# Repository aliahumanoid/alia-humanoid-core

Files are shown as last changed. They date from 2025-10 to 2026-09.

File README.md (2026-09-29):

<p align="center">
  <picture>
    <source media="(prefers-color-scheme: dark)" srcset="docs/media/alia-banner-dark.png">
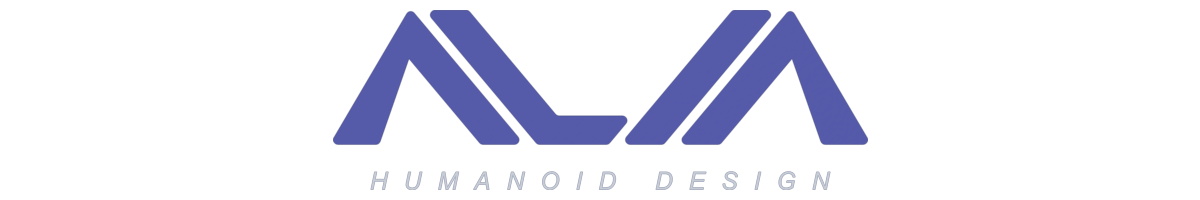
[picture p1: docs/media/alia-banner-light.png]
Alia - Humanoid Design
    
  </picture>
</p>

# Alia Humanoid

**Building humanoid mechanics inside real human proportions.**



<table>
<tr>
<td width="70%">
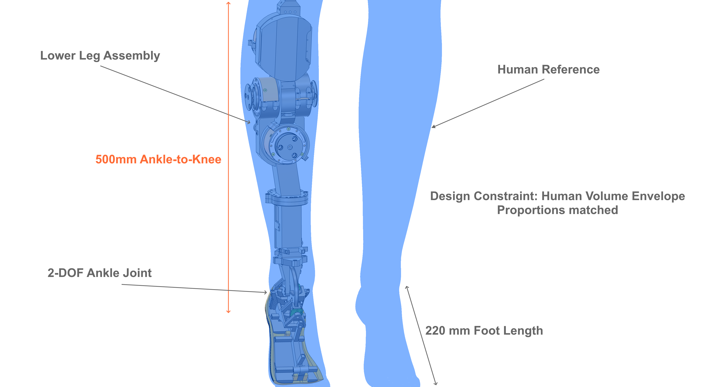
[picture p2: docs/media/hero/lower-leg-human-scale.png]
Lower Leg Human Scale

</td>
<td width="30%">
<a href="https://youtu.be/1Z9GlTnYEFs">
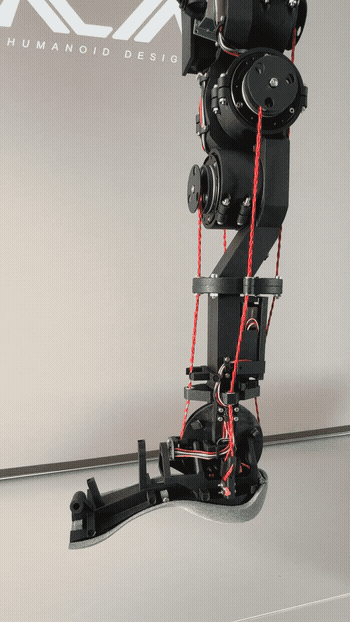
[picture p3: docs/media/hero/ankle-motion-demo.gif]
Ankle motion demo (2 DOF)
  
</a>
</td>
</tr>
<tr>
<td align="center"><i>Lower leg assembly — human scale comparison</i></td>
<td align="center"><i>Right ankle prototype — 2-DOF motion test</i></td>
</tr>
</table>

<table>
<tr>
<td width="65%">
  <a href="https://youtu.be/4jU5Na2z-s8">
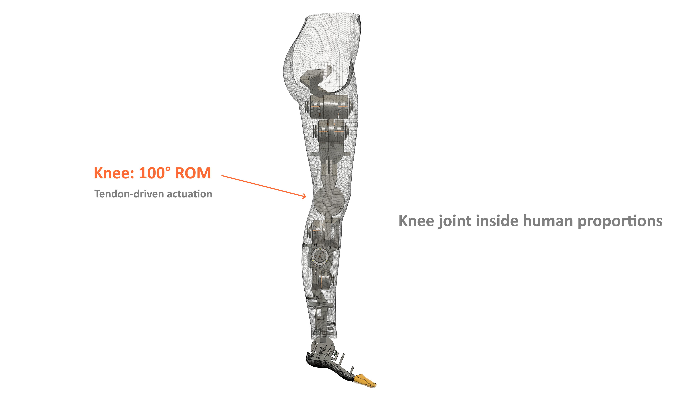
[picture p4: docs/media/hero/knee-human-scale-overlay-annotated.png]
Knee joint overlay (Joint Design Log #002)
    
  </a>
</td>
<td width="35%">
  <a href="https://youtu.be/4jU5Na2z-s8">
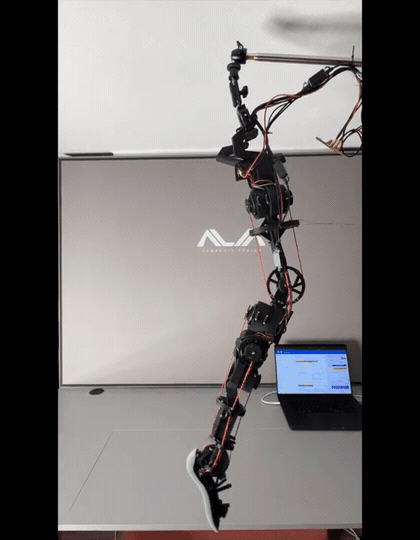
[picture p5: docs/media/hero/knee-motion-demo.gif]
Knee motion demo (1 DOF)
    
  </a>
</td>
</tr>
<tr>
<td align="center"><i>Knee joint overlay — Joint Design Log #002</i></td>
<td align="center"><i>Right knee prototype — 1-DOF motion test</i></td>
</tr>
</table>

<table>
<tr>
<td align="center">
<a href="https://x.com/AliaHumanoid/status/2062545958991265831">
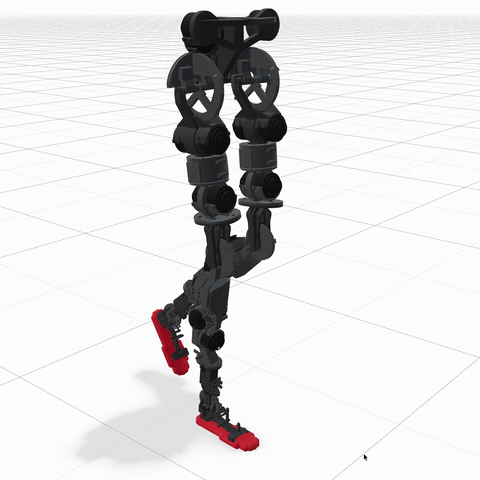
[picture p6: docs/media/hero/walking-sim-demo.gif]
First natural walking gait — physics simulation
  
</a>
</td>
</tr>
<tr>
<td align="center"><i>First natural walking gait — physics simulation, motion-tracking RL (June 2026). Not hardware yet: sim-to-real is gated by remaining hardware.</i></td>
</tr>
</table>

---

## What We're Building

A humanoid robot designed from the ground up to fit within real human dimensions and proportions. 

Most humanoid projects scale UP for easier engineering — more space for motors, looser tolerances, simpler thermal management. We do the opposite: **building inside human constraints** forces design decisions — motor placement, transmission routing, thermal budget — that larger-envelope projects can avoid.

The result? A robot that can fit human environments, wear human clothing, and interact at human scale — using tendon-driven actuation, custom motor placement, and tight mechanical integration.

**Current Phase 0 Focus:** Lower body (hip + knee + ankle) — tendon-driven and direct-drive actuation.

### How We Develop in the Open

This repository carries the **replication core** — firmware, protocols, base host operation, hardware documentation, and results. Advanced lab tooling (calibration campaigns, learning-control experiments, gait tooling) is developed in a private suite and opens progressively as milestones mature. Results, videos, logs, and writeups continue to be published openly. We publish what fails alongside what works; simulation results are labeled as simulation results.

### Latest Updates
- 2026-07: **Development drop** — control-loop rate hardening (bench-validated to 625 Hz on the ankle), joint-map capture improvements, saved-offset warm-boot fast path, MOTION GUARD V2 (gait-aware safety guards; ships disabled, bench validation pending), host impedance-stream `tau_ff` channel — [details](PUBLIC_UPDATES.md)
- 2026-07-18: **Technical note published:** [Deterministic boot-time offset reconstruction for tendon-driven joints](https://aliahumanoid.com/notes/deterministic-boot-offset-reconstruction.html) — method published as prior art
- 2026-07: **License change:** software is GPLv3 from this release (prior MIT snapshots remain MIT); protocol specs stay MIT; hardware licensing unchanged — [rationale](PUBLIC_UPDATES.md)
- 2026-06-04: **First natural walking gait in simulation** — motion-tracking RL on the lower body, ONNX-verified locally — [X thread](https://x.com/AliaHumanoid/status/2062545958991265831) · [details](PUBLIC_UPDATES.md)
- 2026-06: Per-joint power board (`rev_d_power`) bench-validated end-to-end — closed-loop motor control on real hardware, 0.08° tracking error ([report](hardware/electronics/joint_controller_board/rev_d_power/BENCH_VALIDATION_REPORT.md))
- 2026-04: Hip hybrid firmware path implemented (3 DOF / 5 motors) — roll bench bring-up in progress
- 2026-01-26: Joint Design Log #002 (Knee) published — [YouTube](https://youtu.be/4jU5Na2z-s8) · [X thread](https://x.com/AliaHumanoid/status/2015812906101657848)
- 2025-11-13: Joint Design Log #001 (Ankle) published — [YouTube](https://youtu.be/1Z9GlTnYEFs)
- 2025-10-31: Phase 0 public release — [PUBLIC_UPDATES.md](PUBLIC_UPDATES.md)

### Key Features

- 🦶 **2-DOF Ankle Joint**
  Plantarflexion/dorsiflexion (-50° to +25°) + inversion/eversion (±25°)

- 🦵 **1-DOF Knee Joint**
  Full flexion/extension (0° to 100°) with antagonistic tendon pair

- 🦴 **3-DOF Hip Joint (Hybrid)**
  Flexion/extension + abduction/adduction (tendon-driven) + axial roll (direct-drive), 5 motors

- 🧵 **Tendon-Driven Actuation**
  Antagonistic motor pairs with cascade PID, plus single direct-drive for hip roll

- 📏 **Human-Scaled Design**  
  Designed inside real human leg envelope — not scaled up

- ⚙️ **Real Hardware Iteration**  
  PA12 nylon structure (multi jet fusion), pin-and-bushing joints, UHMWPE tendons

- 🖥️ **Jetson Multi-Joint Controller**
  CAN-direct impedance streaming at 50Hz, automated exercise patterns, CAN-first diagnostics

- 🚶 **Walking — In Simulation**
  Natural full-amplitude gait via motion-tracking RL (knee ROM ~57°, foot clearance ~14 cm); sim-to-real gated by remaining hardware

- 📂 **Progressive Open Source**
  Phased licensing roadmap: STL → STEP → CAD source

---

## What Works ✅ / What Doesn't ⚠️

We document **both successes and failures** transparently.

**Current validation snapshot: knee and ankle closed as architecture baselines; per-joint power board bench-validated; hip firmware complete, bench bring-up in progress; natural walking gait achieved in simulation**

### ✅ Validated On Hardware (Phase 0)

- Knee validated as single-controller baseline (`L1` closed) — [Joint Design Log #002](https://youtu.be/4jU5Na2z-s8)
- Ankle validated as single-controller baseline (`L2` closed) — [Joint Design Log #001](https://youtu.be/1Z9GlTnYEFs)
- Multi-joint Jetson coordination operational on bench (`KNEE_RIGHT + ANKLE_RIGHT`) — [milestone log](PUBLIC_UPDATES.md)
- Protocol v1.0 freeze documented for the current knee+ankle bench baseline — [CAN system architecture §4.5](software/docs/CAN_SYSTEM_ARCHITECTURE.md)
- Ankle kinematics achieve target ROM (2 DOF within human envelope) — [joint specs](docs/specs/README.md)
- Knee ROM and tendon-driven position control validated (0-100 degrees)
- UHMWPE tendons validated for current bench loads and pulley compatibility — [tendon specs](docs/specs/TENDON_SPECIFICATIONS.md)
- PA12 structure passes current static/load validation
- Peak torque within biomechanics requirements at the validated bench conditions — [motor specs](docs/specs/MOTOR_SPECIFICATIONS.md)
- Rolling impedance control via CAN with cascade PID on the validated tendon-driven joints — [operational guide](software/docs/SET_IMPEDANCE_OPERATIONAL_GUIDE.md)
- Per-joint power board (`rev_d_power`) validated end-to-end: power rails, hot-swap protection, health telemetry, closed-loop motor control (0.08° tracking error) — [bench report](hardware/electronics/joint_controller_board/rev_d_power/BENCH_VALIDATION_REPORT.md)

### 🧪 Validated In Simulation (Not Hardware)

- Natural full-amplitude walking gait via motion-tracking RL (knee ROM ~57°, foot clearance ~14 cm)
- Policy exported to ONNX and verified locally with observation-parity checks
- Robustness via domain randomization (actuator gains, latency, mass) grounded in measured bench data
- **Honest boundary:** simulation results are simulation results — hardware walking requires foot sole, batteries and full-leg integration first

### 🛠️ Implemented In Firmware, Pending Hip Bench Validation

- Hip hybrid model in firmware (`3 DOF / 5 motors`)
- Per-DOF `DriveType` / `DofCapabilityFlags`
- Direct-drive runtime path for hip axial roll
- Hybrid-aware auto-mapping path (tendon DOFs only)
- `HIP_ROLL_BENCH_*` single-motor bench profiles
- MOTION GUARD V2 — gait-aware divergence/stall guards behind a runtime mode switch (ships in LEGACY mode = current behavior; SHADOW/ACTIVE pending bench validation)

### ⚠️ Still Iterating

- Hip roll bench bring-up and per-DOF gain tuning
- Full hip 3-DOF integrated validation (L3)
- Multi-controller integrated test (L4: hip + knee + ankle on Jetson)
- Walking gait as integrated lower-body system **on hardware**
- Sim-to-real transfer (policy deployment on the onboard computer; gated by foot sole, power boards at scale, batteries)
- Power board high-current stress testing (22A continuous / ~38A peak)

---

## Architecture

```
Jetson host (Python)          RP2350 joint controller (C++)          Motors
SET_IMPEDANCE @50Hz  --CAN-->  core0: encoders (MT6835, SPI)   --CAN--> antagonistic
per-DOF gains/tau_ff           core1: cascade PID + safety              tendon pairs
                               (bench-validated to 625 Hz)              (+ direct-drive hip roll)
```

- [CAN system architecture](software/docs/CAN_SYSTEM_ARCHITECTURE.md) — protocol, IDs, freeze policy
- [SET_IMPEDANCE operational guide](software/docs/SET_IMPEDANCE_OPERATIONAL_GUIDE.md) — the impedance streaming interface
- [Firmware update protocol spec](software/docs/CAN_FIRMWARE_UPDATE_PROTOCOL_SPEC.md) — CAN-based firmware updates

## Build & Run

**Host (runs without hardware):**
```bash
cd software/host && python3 -m venv venv && . venv/bin/activate
pip install -r requirements.txt && python main.py   # web UI on :5001
```

**Firmware (PlatformIO, RP2350 Pico 2):**
```bash
cd software/firmware/joint_controller && pio run
```

Bench bring-up: [Jetson single-controller checklist](software/docs/JETSON_SINGLE_CONTROLLER_BRINGUP_CHECKLIST.md). Minimum bench: one joint controller board, CAN adapter, 24V supply.

## Current Status (Phase 0 — July 2026)

| Component | Status | License | Notes |
|---|---|---|---|
| **Software** | ✅ Public | GPLv3 | Python host + C++ firmware (RP2350 Pico 2); releases before July 2026 remain MIT |
| **Hardware Docs** | ✅ Public | CC BY-NC-ND | Assembly guides, BOM, design specs |
| **STL Files** | ✅ Public | CC BY-NC-ND | 19 files: ankle, lower leg, common components |
| **Electronics** | ✅ Public | CC BY-NC-ND | RP2350 controller board + per-joint power board (KiCad source, Gerber, STEP) |
| **CAD Source** | 📅 Phase 2+ (TBD) | CC BY-SA | Full parametric Fusion 360 timeline |

See our [licensing roadmap](hardware/LICENSE.md) for details on the phased open-source transition.

---

## Quick Links

- 📺 **[YouTube Channel](https://www.youtube.com/@aliahumanoid)** — Design logs, demos, technical breakdowns
- 🐦 **[X/Twitter (@AliaHumanoid)](https://x.com/AliaHumanoid)** — Project updates, iteration logs
- 🌐 **[Website](https://aliahumanoid.com)** — Project overview and roadmap
- 📝 **[Public Updates](PUBLIC_UPDATES.md)** — Public milestone log and release notes
- 📖 **[Documentation](software/README.md)** — Software architecture, protocols, build guides
- 📐 **[Technical Specs](docs/specs/README.md)** — Joint specifications, motor specs, tendon specs
- 🗒️ **[Technical Notes](https://aliahumanoid.com/notes/deterministic-boot-offset-reconstruction.html)** — Method writeups published as prior art

**Evaluating this project? Start here:** (1) watch a [joint design log](https://youtu.be/1Z9GlTnYEFs), (2) read the [boot-reconstruction technical note](https://aliahumanoid.com/notes/deterministic-boot-offset-reconstruction.html), (3) read the firmware control loop (`software/firmware/joint_controller/src/JointController_ControlLoop.cpp`). Issues with findings are welcome.

---

## Gallery

<table>
<tr>
<td width="50%">
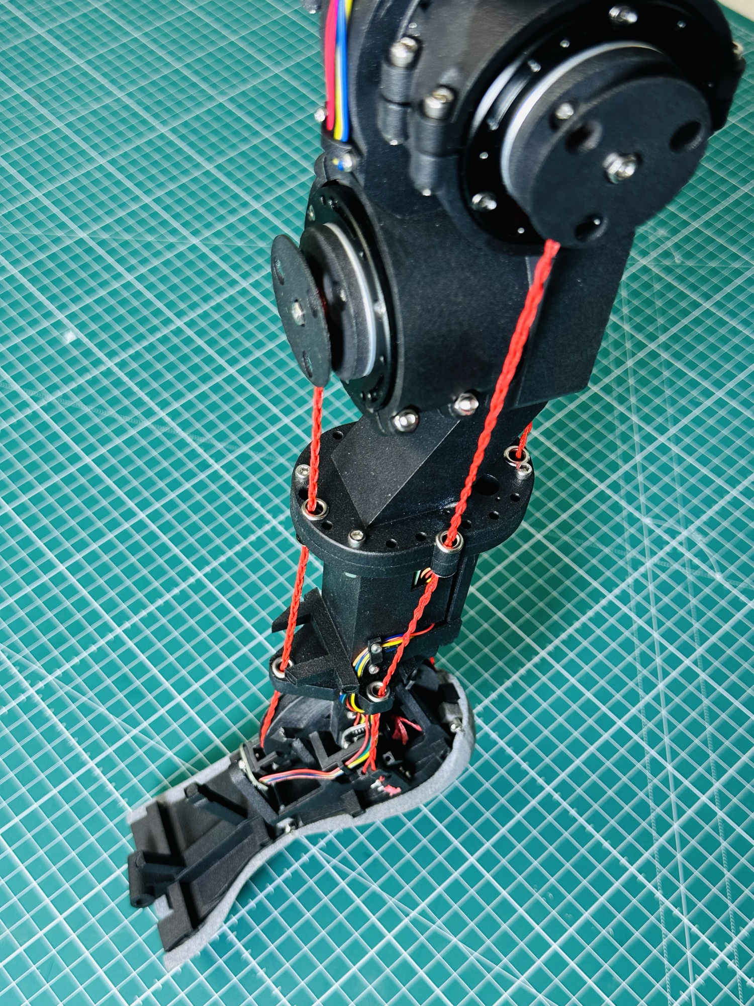
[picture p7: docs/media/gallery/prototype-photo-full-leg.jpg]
Physical Prototype

<p align="center"><i>Physical prototype assembly (Phase 0)</i></p>
</td>
<td width="50%">
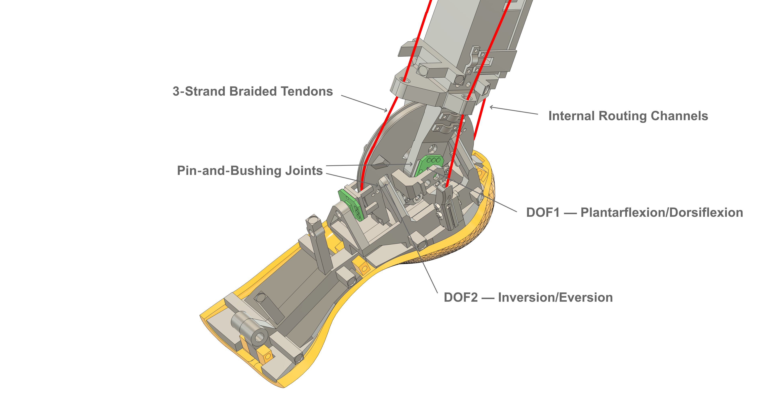
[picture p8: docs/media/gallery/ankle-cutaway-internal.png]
Ankle Internal Mechanisms

<p align="center"><i>Ankle cutaway showing tendon routing</i></p>
</td>
</tr>
</table>

---

## Project Roadmap

### Phase 0 (Current) — Prove the Concept
- **Focus:** Lower body (hip + knee + ankle) validation
- **Release:** Software (GPLv3 from the July 2026 release; earlier snapshots remain MIT), Hardware docs + STL (CC BY-NC-ND)
- **Timeline:** In progress

### Phase 1 — Expand Hardware
- **Focus:** Full leg (hip, knee, ankle), upper body planning
- **Release:** STL → STEP files (CC BY-NC-SA)
- **Timeline:** Planned

### Phase 2 — Full Collaboration
- **Focus:** Complete humanoid system integration
- **Release:** CAD source files (CC BY-SA), governance formalized
- **Timeline:** TBD

### Phase 3 — Open-Core Model
- **Focus:** The software open-core boundary is active now (formalized early, July 2026): this repo = replication core; advanced lab tooling opens progressively as milestones mature
- **Release:** Hardware follows the phased CC roadmap above; private components promote to public at milestone gates
- **Timeline:** Boundary active; promotions ongoing

---

## Follow Progress

This repository documents Phase 0 validation work in public. Small software/docs improvements and evidence-based feedback are welcome. See [CONTRIBUTING.md](CONTRIBUTING.md) for the current collaboration boundary.

**Ground Rules:**
- All commits require DCO sign-off: `git commit -s`
- Use English for code/comments/issues
- Follow conventional commit format (`feat:`, `fix:`, `docs:`, etc.)

**Current Accepted PR Scope:**
- 🐛 Bug reports and fixes
- 📖 Documentation improvements (clarity, examples, translations)
- 🧪 Testing and validation reports (especially hardware replication)
- 💡 Feature proposals (via issues first)

**Not Yet Open As PR Surface:**
- Hardware geometry changes to STL/CAD assets
- Canonical hardware design modifications while the public hardware release remains STL-only

For hardware design ideas, replication findings, and geometry feedback, open an issue first with evidence, measurements, or photos.

---

## References & Acknowledgments

### Control Architecture

The cascade control structure implemented for antagonistic tendon-driven actuation is inspired by the approach described in:

> **Lukić B., Jovanović K., Šekara T. B. (2019).**  
> *Cascade Control of Antagonistic VSA — An Engineering Control Approach to a Bioinspired Robot Actuator.*  
> Frontiers in Neurorobotics, Vol. 13, Article 69.  
> DOI: [10.3389/fnbot.2019.00069](https://doi.org/10.3389/fnbot.2019.00069)

The original paper presents a double-loop cascade architecture for simultaneous position and stiffness control of an antagonistic Variable Stiffness Actuator (VSA). 

In Alia's implementation, this concept has been extended and generalized to a multi-DOF humanoid control system, featuring:
- Coordinated cascade loops for multiple joints
- Per-DOF tuning of PID gains (inner loop: motor position, outer loop: joint position)
- Dynamic modulation of cascade influence and stiffness reference
- Synchronized trajectory generation for agonist–antagonist motor pairs

This implementation is an independent engineering development released under the GNU GPLv3 (releases before July 2026: MIT).

---

## License

- **Software (firmware + host):** [GNU GPLv3](LICENSE) from the July 2026 release onward. Releases published before July 2026 were MIT and remain MIT — irrevocable for anyone who obtained them.
- **Protocol specifications** ([CAN system architecture](software/docs/CAN_SYSTEM_ARCHITECTURE.md), [firmware-update protocol](software/docs/CAN_FIRMWARE_UPDATE_PROTOCOL_SPEC.md)): **MIT**, so third-party tools can integrate without copyleft obligations.
- **Hardware:** unchanged — see [hardware/LICENSE.md](hardware/LICENSE.md) for the phased CC roadmap.

By contributing code, you license it under GPLv3 (DCO sign-off required). Hardware design feedback is welcome now; canonical hardware geometry changes will open later as the hardware release surface expands.

---

### How the pieces fit (what protects what)

| Layer | License / instrument | What it means in practice |
|---|---|---|
| Firmware + host software | **GPLv3** (July 2026 onward; earlier snapshots remain MIT) | Commercial use is allowed; modified versions must stay GPLv3; no locked-down derivatives |
| Protocol specifications | **MIT** | Third-party tools can implement the protocols without copyleft obligations |
| Hardware (STL, docs, BOM) | **CC BY-NC-ND 4.0** today → CC BY-NC-SA (STEP) → CC BY-SA (CAD source) | Print and study now; no commercial use or derivatives yet; opens in phases, see [hardware/LICENSE.md](hardware/LICENSE.md) |
| Published technical notes | **Public prior art** | Keeps the methods free for everyone to use: nobody can patent them later. Prior art does not restrict copying; the licenses above do |
| Name and logo | Not covered by any of the above | Trade mark rules apply separately |

ALIA HUMANOID is a registered EU trade mark (EUTM 019380142). The name and the brand are not covered by the open licenses of this repository.

## Developer Certificate of Origin (DCO)

All commits must include a `Signed-off-by` line to certify you have the right to contribute:

```bash
git commit -s -m "feat: add ankle calibration script"
```

This asserts compliance with the [Developer Certificate of Origin](https://developercertificate.org/).

---

## Contact

- **General:** info@aliahumanoid.com
- **Issues/PRs:** Use GitHub issues and pull requests
- **Social:** [@AliaHumanoid](https://x.com/AliaHumanoid) on X/Twitter

---

**Project Status:** Phase 0 active development

---

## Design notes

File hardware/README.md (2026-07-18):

# Alia Humanoid Hardware

**Project Phase**: 0 (public lower-body validation)  
**Status**: Lower leg assets preparation (ankle validated)  
**Current Public Hardware Release**: STL/docs/BOM only  
**License**: CC BY-NC-ND 4.0 → See [LICENSE.md](LICENSE.md)

---

## Overview

This directory contains all mechanical design assets for the Alia humanoid robot. CAD files, STL exports, URDF models, and manufacturing documentation are organized following ROS/URDF naming conventions for seamless simulation integration.

If you just want the currently released printable STL parts, start here:

- [Simple STL Release](stl/phase0_rev_a/)
- [Mechanical Release Guide](mechanical/README.md)
- [Electronics Hardware](electronics/)
- [Hardware License](LICENSE.md)

## Directory Structure

```
hardware/
├── urdf/              → URDF/xacro files for robot simulation
│   ├── alia.urdf      → Complete robot description
│   ├── materials.xacro
│   └── joints/        → Individual joint URDF macros
│
├── meshes/            → 3D meshes for visualization & collision
│   ├── visual/        → High-quality STL for RViz/Gazebo rendering
│   └── collision/     → Simplified collision meshes (performance)
│
├── stl/               → Simple public STL release entrypoint
├── mechanical/        → CAD sources & manufacturing files
│   ├── BOM.csv        → Bill of Materials (complete parts catalog)
│   ├── lower_leg/     → Shank structure (tibia/fibula analog)
│   ├── ankle/         → 2-DOF ankle joint (validated Phase 0)
│   └── foot/          → Foot base + phalanges (5 toes)
│
└── electronics/       → Public PCB designs (controller logic board + passive hubs)
    ├── joint_controller_board/  → RP2350 controller logic board (`rev_d_logic`)
    ├── MT6835_hub_rev_a/        → Passive encoder SPI hub
    └── motor_can_power_hub_rev_a/ → Passive CAN/power distribution hub
```

---

## Released STL Files (Phase 0)

**19 files currently available for printing.**

Simple download path:

- [hardware/stl/phase0_rev_a](stl/phase0_rev_a/)

Traceable mechanical source paths are listed below.

### Right Ankle Assembly (6 parts)
- `ankle_inversion_eversion_frame.stl` — Main frame for inversion/eversion motion
- `ankle_plantar_dorsal_frame.stl` — Frame for plantarflexion/dorsiflexion motion  
- `ankle_tendon_holder_left.stl` — Tendon anchor point (left side)
- `ankle_tendon_holder_right.stl` — Tendon anchor point (right side)
- `ankle_tendon_holder_inversion_left.stl` — Inversion tendon mount
- `ankle_tendon_holder_inversion_right.stl` — Inversion tendon mount

### Right Lower Leg Assembly (4 parts)
- `lower_leg_frame_upper.stl` — Upper leg structure
- `lower_leg_frame_lower.stl` — Lower leg structure
- `lower_leg_encoder_board_cover.stl` — Encoder electronics cover
- `lower_leg_power_board_cover.stl` — Power distribution cover

### Common Components (9 parts)
**Motor mounts:**
- `motor_mount_mg4005.stl` — Mount for LKM MG4005 motors
- `motor_mount_mg5010.stl` — Mount for LKM MG5010 motors

**Pulleys:**
- `pulley_10mm.stl` — 10mm diameter pulley for tendon routing
- `pulley_18mm.stl` — 18mm diameter pulley for tendon routing

**Sensor mounts:**
- `encoder_mount_mt6835_flat.stl` — MT6835 encoder mount (flat)
- `encoder_mount_mt6835_with_spacer.stl` — MT6835 encoder mount (with spacer)
- `shaft_holder_flat.stl` — Shaft retainer (flat version)
- `shaft_holder_with_spacer.stl` — Shaft retainer (with spacer)

**Cable management:**
- `cable_clamp_10mm.stl` — Cable routing clamp

**Material:** PA12 (nylon) recommended. Print settings and BOM available in component directories.

---

## Naming Convention

**Standard**: ROS/URDF snake_case for maximum compatibility with robotics ecosystem.

### File Naming Format
```
{body_part}_{component}_{descriptor}.{ext}

Examples:
- lower_leg_shank_upper.step
- ankle_pulley_proximal.stl
- foot_toe_01.step (big toe / hallux)
```

### Left/Right Handling
**Directory-based separation** (not filename suffix):
```
mechanical/ankle/
├── left/
│   └── rev_a/
│       └── stl/
│           └── ankle_pulley_proximal.stl  ← Same name for L/R
└── right/
    └── rev_a/
        └── stl/
            └── ankle_pulley_proximal.stl  ← Different path, identical filename
```

**Rationale**: Enables URDF xacro macros to reference parts with parameter substitution:
```xml
<mesh filename="package://alia_description/meshes/ankle/${side}/ankle_pulley_proximal.stl"/>
```

### Revision Management
```
mechanical/{joint}/{side}/
├── rev_a/     → Initial design (current)
├── rev_b/     → Future iteration
└── rev_c/     → Further refinement
```

**Revision Policy**:
- Increment letter (A→B→C) when **geometry/dimensions change**
- Track material/finish changes in BOM notes (no new revision)
- Keep all revisions in Git for traceability

## Contributing

For the current STL-only release, hardware feedback is welcome but canonical hardware geometry changes are not part of the active PR surface yet.

Current in-scope contributions:
1. Replication feedback with measurements, photos, and failure notes
2. Documentation fixes and clarifications
3. BOM corrections or missing-public-data corrections
4. Issues that identify manufacturability or assembly problems

When STEP/CAD sources are released, hardware geometry collaboration will expand. See the root [CONTRIBUTING.md](../CONTRIBUTING.md) and [LICENSE.md](LICENSE.md) for the current boundary.

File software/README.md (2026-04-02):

# Software Stack

This directory contains the public software stack for the Alia project.

Structure
```
software/
├─ host/                 # Python host application (Flask + Socket.IO)
└─ firmware/             # Embedded firmware projects (PlatformIO)
```

Current Status
- Firmware and host application integrated and operational
- Repository structure consolidated for public development
- Build system and tooling fully configured

Operational docs
- `docs/CAN_SYSTEM_ARCHITECTURE.md` - wire-level host↔controller protocol and transport architecture
- `docs/CAN_DIAGNOSTICS_OPERATIONAL_GUIDE.md` - CAN-first observability workflow for integrated experiments
- `docs/SET_IMPEDANCE_OPERATIONAL_GUIDE.md` - operational semantics for impedance commands

Dev Runner

Use the Makefile to switch between running the host app and building firmware.

- `make run MODE=host` — run Python host (creates venv, installs deps)
- `make run MODE=firmware-controller ENV=pico2` — build controller firmware
- `make fw-monitor-controller PORT=/dev/tty.usbmodemXXXXX` — serial monitor 115200

PlatformIO path (optional)
- If you don't have `pio` globally, PlatformIO is also installed inside the host venv.
- Pass `PIO=host/.venv/bin/pio` to Makefile targets, e.g.:
  - `make run MODE=firmware-controller ENV=pico2 PIO=host/.venv/bin/pio`

Flash & Monitor via VS Code
- You can use the PlatformIO VS Code extension to upload/monitor without CLI.
- Open `software/firmware/joint_controller` as a project in VS Code and use the PIO toolbar (Upload, Monitor).

Host notes
- The dev server uses Werkzeug with `allow_unsafe_werkzeug=True` for local runs only.
- For production-like tests, prefer a proper SocketIO server (e.g., `eventlet` or `gunicorn` + `gevent`).

Host quickstart (manual)
- `cd software/host && python3 -m venv .venv && source .venv/bin/activate`
- `pip install -r requirements.txt`
- `python main.py` then open `http://localhost:5001`

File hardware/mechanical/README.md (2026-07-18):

# Mechanical Release Guide

This is the direct entrypoint for the currently released mechanical assets.

## Start Here

The current public Phase 0 release is centered on the **right lower leg + right ankle** plus reusable common hardware.

For the simplest STL download path, use:

- [hardware/stl/phase0_rev_a](../stl/phase0_rev_a/)

Released printable parts live in:

- [ankle/right/rev_a/stl](ankle/right/rev_a/stl)
- [lower_leg/right/rev_a/stl](lower_leg/right/rev_a/stl)
- [common](common)
- [BOM.csv](BOM.csv)

## What Is Released Now

- Right ankle STL set
- Right lower-leg STL set
- Common motor mounts, pulleys, sensor mounts, and cable-management parts
- Phase 0 BOM

## What Is Not a Public Build Surface Yet

These directories exist for structure and future release flow, but they are not the main public printing path today:

- `ankle/left/`
- `lower_leg/left/`
- `foot/`
- `rev_a/cad/`
- `rev_a/docs/`
- `rev_a/manufacturing/`

Treat them as repository structure, work-in-progress, or future release surface unless a component directory explicitly says otherwise.

## Practical Path

If you want to print the current public lower-body set:

1. Read [hardware/README.md](../README.md) for scope and license.
2. Use the STL folders listed above.
3. Cross-check quantities and hardware callouts in [BOM.csv](BOM.csv).
4. Use [PUBLIC_UPDATES.md](../../PUBLIC_UPDATES.md) for release context.

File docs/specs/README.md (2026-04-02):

# Technical Specifications — Alia Humanoid

> **Status**: Phase 0 Reference Documentation  
> **Last Updated**: 2026-03-07

---

## Overview

This directory contains authoritative technical specifications for all mechanical subsystems of the Alia humanoid robot.

**Purpose**:
- Documentation consistency across public specs and implementation
- Public technical reference and content creation
- Future collaborator onboarding
- BOM management

---

## Specification Documents

| Document | Scope | Status |
|---|---|---|
| [ANKLE_SPECIFICATIONS.md](ANKLE_SPECIFICATIONS.md) | 2-DOF ankle joint (kinematics, motors, transmission) | ✅ Validated |
| [KNEE_SPECIFICATIONS.md](KNEE_SPECIFICATIONS.md) | 1-DOF knee joint | ✅ Validated |
| [MOTOR_SPECIFICATIONS.md](MOTOR_SPECIFICATIONS.md) | QDD motor classes (50mm, 40mm) | Phase 0 |
| [TENDON_SPECIFICATIONS.md](TENDON_SPECIFICATIONS.md) | UHMWPE tendons, routing, terminations | Phase 0 |

---

## Robot Parameters

| Parameter | Value |
|---|---|
| Target Height | 175 cm |
| Target Mass | 25 kg |
| Design Gait | Slow walking |
| Actuation | Antagonistic tendon-driven |

---

## Validation Status

| Joint | ROM | Torque | Control | Integration |
|---|-----|---|---|---|
| Ankle | ✅ | ✅ | ✅ | 🔄 In progress |
| Knee | ✅ | ✅ | ✅ | 🔄 In progress |
| Hip | — | — | — | ⏳ Planning |

---

## Document Conventions

### Status Indicators

| Symbol | Meaning |
|---|---|
| ✅ | Validated / Complete |
| ⚠️ | Needs attention / Partial |
| 🔄 | In progress |
| ⏳ | Planned / Future |
| [TBD] | To Be Determined |

### Units

- Linear: mm (millimeters)
- Angular: degrees (°)
- Torque: Nm (Newton-meters)
- Force: N (Newtons)
- Mass: g or kg
- Speed: RPM or °/s

---

## Related Documentation

| Location | Content |
|---|---|
| `../../software/docs/CAN_SYSTEM_ARCHITECTURE.md` | CAN architecture, protocol, and streaming |
| `../../hardware/mechanical/BOM.csv` | Bill of Materials |
| `../../software/firmware/` | Controller firmware |

---

## Contributing

Specification updates require:
1. Engineering validation (test data)
2. Decision-log entry (if disclosure-sensitive)
3. Version increment in document control section

---

**Next Review**: After next lower-body validation checkpoint

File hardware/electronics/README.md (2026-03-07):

# Alia Humanoid Electronics

**Status:** Public release scoped to the current controller logic board and two passive hubs  
**License:** CC BY-NC-ND 4.0 (Phase 0) → See [hardware/LICENSE.md](../LICENSE.md)

---

## Overview

This directory contains the electronics currently exposed in the public repository. Older controller revisions and internal support files are intentionally excluded from publication.

## Published Boards

### `joint_controller_board/rev_d_logic`

Main RP2350 logic/control board for one joint.

- RP2350 Pico 2 host module
- Two onboard CAN channels (`MCP2515 + SN65HVD230`)
- RJ45 interface for encoder and power/safety breakout
- KiCad source, BOM, and current fabrication package

### `MT6835_hub_rev_a`

Passive encoder hub that fans out up to three MT6835 SPI encoders into the RJ45 encoder port used by `rev_d_logic`.

- KiCad source
- BOM
- Current fabrication package

### `motor_can_power_hub_rev_a`

Passive CAN/power distribution board for motor wiring.

- XT60 power input
- CAN input terminal block
- Five motor harness outputs
- KiCad source, BOM, and current fabrication package

## Directory Structure

```text
electronics/
├── joint_controller_board/
│   └── rev_d_logic/
├── MT6835_hub_rev_a/
└── motor_can_power_hub_rev_a/
```

---

**Questions?** Contact us at info@aliahumanoid.com

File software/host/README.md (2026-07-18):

# Host Application (Python/Flask)

Web-based control interface for the Alia humanoid joint controller system. This application provides real-time monitoring, PID tuning, auto-mapping, and multi-DOF movement control.

## Features

- **Real-time Joint Control**: Web UI for controlling multiple joints with up to 3 DOF each
- **PID Tuning**: Live adjustment of inner and outer loop PID parameters
- **Auto-Mapping**: Automatic calibration and linear equation generation
- **Multi-DOF Movements**: Coordinated movements with different path types and synchronization strategies
- **Encoder Testing**: Real-time encoder data streaming and visualization
- **Serial Management**: Multi-device serial communication with automatic port detection
- **Structured CAN Diagnostics**: Per-joint health, fault, event, and snapshot history persisted as JSONL

## Quick Start

**Requirements**: Python 3.11+

```bash
cd software/host
python3 -m venv .venv && source .venv/bin/activate
pip install -r requirements.txt
python main.py
```

Open browser at: `http://localhost:5001`

## Joint Configuration Sync

The host application automatically loads joint definitions from `software/joint_config.json`, which is generated from the firmware's `config_presets.h`. This ensures firmware and host stay synchronized.

**To update joint configurations:**
1. Edit `software/firmware/joint_controller/include/config_presets.h`
2. Run: `python software/scripts/extract_joint_config.py`
3. Restart the host application

See `software/docs/JOINT_CONFIG_SYNC.md` for details.

For integrated experiments and Jetson bring-up, see
`software/docs/CAN_DIAGNOSTICS_OPERATIONAL_GUIDE.md`.

## Project Structure

- `main.py` - Application entry point
- `config.py` - Configuration (loaded from joint_config.json)
- `routes.py` - Flask API routes
- `diagnostic_history.py` - JSONL persistence for structured CAN diagnostics
- `bench_diagnostics.py` - Windowed summaries for bench diagnostic JSONL histories
- `serial_handler.py` - Serial protocol implementation
- `serial_manager.py` - Multi-device serial management
- `templates/` - HTML templates (Alia Joint Controller UI)
- `static/` - JavaScript, CSS, images
- `logs/` - Session logs (gitignored)
- `mapping_data/` - Auto-mapping data storage (local runtime data, gitignored)
- `can_config.json` - Saved CAN interface selection (created locally, gitignored)

## Development Workflows

### Using Makefile (Recommended)

From `software/` directory:
```bash
make run MODE=host
```
This automatically creates venv, installs dependencies, and runs the server.

### VS Code

Open the repository root or `software/host/`, select the local `.venv` interpreter, and run `main.py`.

### Firmware Builds (Optional)

Build firmware from the same Makefile:
```bash
make run MODE=firmware-controller ENV=pico2
```

If PlatformIO is not in PATH, specify venv:
```bash
PIO=host/.venv/bin/pio make run MODE=firmware-controller ENV=pico2
```

### Flash & Monitor via VS Code

Use PlatformIO extension in VS Code:
1. Open `software/firmware/joint_controller`
2. Use PIO toolbar to upload and monitor

## Environment Variables

- `FLASK_HOST` - Server host (default: `0.0.0.0`)
- `FLASK_PORT` - Server port (default: `5001`)
- `FLASK_DEBUG` - Debug mode (default: `False`)
- `BAUD_RATE` - Serial baud rate (default: `115200`)

## Notes

- Logs are written under `logs/` (gitignored)
- Structured diagnostic histories are written under `logs/diagnostic_history/` (gitignored)
- `mapping_data/` stores auto-mapping results (gitignored)
- `can_config.json` is created after a successful CAN connection and remains local (gitignored)
- Dev server uses `allow_unsafe_werkzeug=True` for Flask-SocketIO compatibility (local dev only)
- On macOS with a CANable flashed to `candleLight`, the reliable host path is
  currently `interface: candle` at `500 kbps`. The repo default still points to
  `slcan`, so bench runs may require a local config override.
- On the same macOS bench, USB enumeration can be visible at the OS level while
  process-local autodetect still returns no CAN adapters. If that happens,
  verify the device in system USB info first, then force the `candle` backend
  explicitly instead of relying on autodetect.

## Bench Diagnostics

For repeatable bench-motion diagnostics, record one exercise window and then
summarize only that time slice from the structured JSONL history:

```bash
cd software/host
python3 -m jetson_controller.exercise --joint hip_roll_bench_right --report-json /tmp/hip_roll_run.json ...
python3 tools/analyze_bench_diagnostics.py --report /tmp/hip_roll_run.json
```

The report anchors the movement window, and the analyzer summarizes:
- health counter deltas
- active fault counts
- event counts
- loop timing samples from `HEALTH_STATUS`
- Rev D power-board status when `HEALTH_STATUS` extension `0x82` is present

## CAN adapter on macOS (CANable2 / candleLight)

The bench CANable2 runs `candleLight` (gs_usb) firmware, not `slcan`. The committed
`controller.yaml` defaults to `interface: slcan` and does **not** work with this adapter,
so the gs_usb path requires a local config override (`controller.yaml` is left untouched).

**Working path: the `candle` interface under arm64.** Notes:
- The venv needs `python-can-candle` (1.2.4) + `candle_api` (0.0.12) installed under arm64.
- Use `controller_candle_bench.yaml` (`interface: candle`, `channel: auto`,
  `bitrate: 500000`) and pass it via `--config`.
- Adapter observed at host CAN bitrate 500 kbps (candle channel id
  `001A00473945501720303651:0`); Pico 2 USB CDC serial at `/dev/cu.usbmodem1401`.

**sudo / DYLD pitfall:** the universal `/usr/local/bin/python3` runs x86_64 by default, so
the arm64 `candle_api` binding fails to load. The raw gs_usb backend needs `sudo` **and**
libusb, but `sudo` strips `DYLD_*` so pyusb cannot find libusb — a dead end. The `candle`
interface under arm64 avoids this and works **without** sudo. For ad-hoc reads use
`arch -arm64 /usr/local/bin/python3` with `python-can-candle`.

**Launch (CAN-only TUI):**
```bash
./jetson_controller/run_hip_roll_bench_right_can_only.sh \
  --config <abs path to controller_candle_bench.yaml>
```

> The dual-pane `run_hip_roll_bench_right.sh` wrapper is currently broken for this use:
> `run.sh` `both` mode rejects the `--joint` pass-through arg. Use the `_can_only` variant.

## License

GPLv3 (from the July 2026 release; earlier MIT snapshots remain MIT) - see repository root `LICENSE` file.

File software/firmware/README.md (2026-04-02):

# Firmware Projects

Embedded firmware for the Alia humanoid joint control system, maintained as part of the public repository.

## Projects

- **`joint_controller/`** — Dual CAN motor control, rolling-impedance control, and cascade PID (Raspberry Pi Pico 2 / RP2350)

> **Note**: The legacy `joint_encoders/` project has been retired. MT6835 encoders are now read directly by the joint controller via SPI0.

## Board Selection

**Current target**: Raspberry Pi Pico 2 (RP2350).

The RP2350 provides:
- Dual Cortex-M33 cores @ 150MHz
- 520KB SRAM (sufficient for multi-DOF movement planning)
- Enhanced peripheral support
- Pin-compatible with original Pico for easy migration

## Quick Build

```bash
# From software/ directory
make run MODE=firmware-controller ENV=pico2

# Or directly with PlatformIO
cd joint_controller && ~/.platformio/penv/bin/pio run
```

See `joint_controller/README.md` for detailed build instructions, protocol documentation, and safety considerations.

## Third-Party Libraries

| Library | License | Source |
|---|---|---|
| **mcp_can** v1.5.1 | LGPL-3.0 | [coryjfowler/MCP_CAN_lib](https://github.com/coryjfowler/MCP_CAN_lib) |

The `mcp_can` library is vendored in `joint_controller/lib/mcp_can/` with its original license file.

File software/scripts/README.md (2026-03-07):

# Software Scripts

Utility scripts for the Alia Humanoid software stack.

## Scripts

### `extract_joint_config.py`

**Purpose**: Extract joint configuration from firmware and generate JSON for host application.

**Usage**:
```bash
# Using default paths
python3 extract_joint_config.py

# Custom paths
python3 extract_joint_config.py <input_config.h> <output_config.json>

# Via Makefile (recommended)
cd ..
make joint-config
```

**Input**: `firmware/joint_controller/include/config_presets.h`  
**Output**: `joint_config.json`

**What it does**:
1. Parses C++ firmware configuration using regex
2. Extracts joint IDs, DOF counts, angle limits, motor counts
3. Generates structured JSON with all joint data
4. Validates consistency and reports issues

**When to run**:
- **Automatically**: When building `joint_controller` firmware (post-build hook)
- After modifying `config_presets.h` (if not building firmware)
- When adding/removing joints
- When changing angle limits or DOF counts
- Automatically via `make host-run` (Makefile integration)

**See also**: `docs/JOINT_CONFIG_SYNC.md` for detailed documentation

---

### Firmware Scripts

These scripts are located in `firmware/joint_controller/scripts/` and are automatically invoked by PlatformIO during build:

#### `firmware/joint_controller/scripts/generate_joint_config.py`

**Purpose**: Post-build hook to automatically regenerate `joint_config.json` after firmware build.

**When it runs**: Automatically after successful firmware compilation (any environment: pico2, pico2_debug)

**What it does**:
1. Runs after firmware `.elf` is built
2. Calls `extract_joint_config.py` with correct paths
3. Regenerates `joint_config.json` in `software/` directory
4. Prints status messages during build
5. Non-blocking: warns if generation fails but doesn't fail build

**Integration**: Configured via `extra_scripts = post:scripts/generate_joint_config.py` in `platformio.ini`

**Benefits**:
- ✅ Zero manual intervention: build firmware → JSON auto-updated
- ✅ Impossible to forget: every build ensures sync
- ✅ Fast iteration: change config, rebuild, done

## Directory Structure

```
scripts/
├── README.md                      # This file
└── extract_joint_config.py        # Joint config extractor
```

## Adding New Scripts

When adding utility scripts to this directory:

1. **Make executable**: `chmod +x script_name.py`
2. **Add shebang**: `#!/usr/bin/env python3` (first line)
3. **Document usage**: Update this README
4. **Integrate**: Add to Makefile if appropriate
5. **Test**: Verify script works in clean environment

## Requirements

Python 3.7+ (uses `pathlib`, f-strings)

No external dependencies required for current scripts.

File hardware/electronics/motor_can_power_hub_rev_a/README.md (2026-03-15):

# Motor CAN/Power Hub Rev A

## Scope
Passive hub board for LKM MG5010E v3 motor wiring.

Board functions:
- Receive CAN bus from `joint_controller` via 3-pin screw terminal (`GND`, `CAN_L`, `CAN_H`)
- Receive 24V power via XT60 (same family used on joint_controller)
- Distribute power/CAN harness to 5 motor ports (6-pin each)

## Project files
- `motor_can_power_hub_rev_a.kicad_sch`
- `motor_can_power_hub_rev_a.kicad_pcb`
- `motor_can_power_hub_rev_a.kicad_pro`
- `motor_can_power_hub_rev_a.step`

## Connectors placed in schematic (with footprints)
- `J_PWR_IN`: XT60 input
  - Footprint: `Connector_AMASS:AMASS_XT60PW-M_1x02_P7.20mm_Horizontal`
- `J_CAN_IN`: CAN screw terminal 3-pin
  - Footprint: `TerminalBlock_Phoenix:TerminalBlock_Phoenix_MPT-0,5-3-2.54_1x03_P2.54mm_Horizontal`
- `J1..J5`: motor harness connectors 6-pin
  - Footprint: `Connector_JST:JST_ZH_B6B-ZR_1x06_P1.50mm_Vertical`

## Cable mating rule
Board connectors are male headers, therefore cables must be **female-female**.

## Current pin mapping (J_MOTOR1..J_MOTOR5)
Per connector, pin mapping is currently set to:
- Pin 1: `CAN_L`
- Pin 2: `CAN_H`
- Pin 3: `V--`
- Pin 4: `V--`
- Pin 5: `V++`
- Pin 6: `V++`

## CAN/power input mapping
- `J_CAN_IN1`:
  - Pin 1: `CAN_GND` (tied to `V--`)
  - Pin 2: `CAN_L`
  - Pin 3: `CAN_H`
- `J_PWR_IN1`:
  - Pin 1: `V--`
  - Pin 2: `V++`

## Verification status (2026-02-26)
- ERC: 0 violations
- DRC: 0 violations, 0 unconnected
- Schematic/PCB parity: 0 issues

## Fabrication BOM

Verified manufacturing BOM:
- `BOM_fabrication.csv`

Included lines:
1. `J_PWR_IN1` -> `AMASS XT60PW-M` (THT)
2. `J_CAN_IN1` -> `Phoenix Contact 1725669` (THT)
3. `J_MOTOR1-J_MOTOR5` -> `JST B6B-ZR(LF)(SN)` (THT)

## Fabrication package
Generated package path:
- `fabrication_release_2026-02-27_refresh/motor_can_power_hub_rev_a_fabrication_release_2026-02-27_refresh.zip`

Package includes:
- Gerbers (`F/B Cu`, `F/B Mask`, `F/B Silkscreen`, `Edge_Cuts`)
- Excellon drill (`.drl`)
- Drill map (`-drl_map.pdf`)
- Job file (`.gbrjob`)
- `BOM_fabrication.csv`

## 3D Models

This project includes local connector STEP models under `3dmodels/` for the JST ZH and XT60 footprints referenced by the PCB.

## Drill check (2026-02-27 refresh)
- Minimum finished drill in generated Excellon file: `0.60 mm`
- Constraint check against the selected fabrication baseline (`>= 0.20 mm`): **PASS**

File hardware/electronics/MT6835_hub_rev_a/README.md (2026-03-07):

# MT6835 Hub Rev A

Passive breakout board that routes up to three MT6835 SPI encoder modules into the RJ45 encoder port used by `joint_controller_board/rev_d_logic` (`J2`).

## Purpose

- Aggregate three encoder channels into one RJ45 link
- Preserve the SPI pin mapping expected by the controller board
- Keep the hub fully passive: no active components, only connector routing

## RJ45 Output Pinout

This connector maps directly to `rev_d_logic` encoder connector `J2`.

1. `GND`
2. `SCK`
3. `MOSI`
4. `MISO`
5. `CS1`
6. `CS2`
7. `CS3`
8. `+5V`

## Encoder Input Connectors (`J1/J2/J3`)

Each encoder connector is a 6-pin SPI header:

1. `GND`
2. `CSx`
3. `SCK`
4. `MOSI`
5. `MISO`
6. `+5V`

## Connector Family

The board uses 1.25 mm PicoBlade connectors for the encoder side.

- PCB footprint: `Molex_PicoBlade_53398-0671_1x06-1MP_P1.25mm_Vertical`
- Board header: `Molex 53398-0671`
- Matching cable housing: `Molex 51021-0600`
- Matching crimp terminal: `Molex 50079-8100`

## Verification Status

Latest checks on the current board revision:

- ERC: 0 violations
- DRC: 0 violations
- Unconnected pads: 0
- Schematic/PCB parity: 0 issues

## Included Files

- `MT6835_hub_rev_a.kicad_sch`
- `MT6835_hub_rev_a.kicad_pcb`
- `MT6835_hub_rev_a.kicad_pro`
- `MT6835_hub_rev_a.step`
- `BOM_fabrication.csv`
- `BOM_kicad_grouped.csv`
- `fabrication_release_2026-02-27_fix_drill/MT6835_hub_rev_a_fabrication_release_2026-02-27_fix_drill.zip`

## Notes

- This board carries only connector routing and power distribution for SPI encoder lines.
- The `fix_drill` fabrication package is the current release candidate for manufacturing.

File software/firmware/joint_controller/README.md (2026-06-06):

# Joint Controller — Robotic Joint Control System

## Build Quickstart (EN)

- Requirements: PlatformIO (VS Code extension or CLI), Internet on first build.
- Board/Env: `pico2` (Arduino core: Earle Philhower for RP2350).
- Serial monitor speed: `115200`.

Commands (from this folder):
```
pio run -t clean -e pico2   # Clean
pio run -e pico2            # Build
pio run -e pico2 -t upload  # Upload (when a Pico 2 is connected)
pio device monitor -b 115200
```

Notes:
- Keep all protocol messages that start with `EVT:` unchanged; they are used by the host application.
- This project targets Raspberry Pi Pico 2 (RP2350) with dual Cortex-M33 cores.

### Rev D Split Power-Board Integration (`pico2_debug_rev_d`)

The Rev D split power-board integration is bench-validated end-to-end with a real motor
(`hip_roll_bench_right`, joint `8`): bare board → rails → TPS2492 hot-swap path → telemetry →
FAULT handling → closed-loop control. The `0x82` HEALTH power-board telemetry frame
(`DIAG_HEALTH_EXT_POWER_BOARD_STATE`) is emitted and decoded end-to-end at the host.

Two firmware refinements landed in `src/power_board_rev_d.cpp` during bring-up:
- ADC reference is now overridable via `-DPOWER_BOARD_ADC_REF_MV` (default `3300`, no behaviour
  change) for per-board calibration of the `3V3_AUX` rail.
- `FAULT_N` startup blanking (`FAULT_STARTUP_BLANK_MS = 100`) suppresses the one-shot boot glitch
  during GPIO/pull-up settling; real faults past the window are still detected/counted.

High-current stress (Phase 7) and TPS2492 hardware overcurrent latch-off are not yet exercised.
Board design docs: `hardware/electronics/joint_controller_board/rev_d_power/`.

## Overview
This firmware implements the control system for a tendon‑driven robotic joint actuated by up to 4 LKM motors. It runs on a Raspberry Pi Pico 2 (RP2350) and controls motors over CAN.

## System Architecture

### Hardware
- **Microcontroller**: Raspberry Pi Pico 2 (RP2350)
- **Motors**: Up to 4x LKM motors (Motor CAN bus)
- **Joint Encoders**: Up to 3x MT6835 magnetic encoders via SPI0 (direct reading, one per DOF)
- **Communication**:
   - **Host CAN** (MCP2515, GP08 CS): Impedance targets, commands, telemetry (Host/Jetson ↔ Controller)
   - **Motor CAN** (MCP2515, GP09 CS): Torque commands, status (Controller ↔ Motors)
   - **SPI0**: Direct encoder reading (MT6835)
   - **Serial** (USB CDC): Diagnostics only (disconnected in production)

### Main Software Components

#### 1) LKM_Motor class
Motor control and CAN protocol for LKM motors:
 - Position, speed and torque control
 - Integrated encoder handling: inversion, offset, reduction compensation
 - Synchronous/asynchronous reads
 - Single‑loop and multi‑loop angle commands, incremental moves

#### 2) Encoders class
SPI reader for the external joint encoder:
- Synchronous joint angle readout
- Sync sequence handling and data validation
- Optional direction inversion and angle offsets

#### 3) Mapping system
Implements the relation between joint angle and motor angles:
- Automatic mapping procedures
- Interpolation/extrapolation (processed datasets)
- Flash save/load of compact linear equations and limits

#### 4) Motion control
- Rolling-impedance targets via CAN (SET_IMPEDANCE frames)
- Cascade PID: outer position loop + inner torque loop
- Tendon pretensioning and safety supervision
- Performance monitoring (movement metrics, smoothness)

### Key Features

#### Calibration
1. **Zero finding**
   - Automatic routine to find joint zero
   - Tendon pretension management
   - Encoder offset calibration

2. **Joint mapping**
   - Automatic creation of joint→motor angle mapping
   - Pretension handling during mapping
   - Validation and flash storage (compact equations)

#### Motion
1. **Impedance control**
   - Rolling impedance targets via CAN (position + stiffness + damping)
   - Cascade PID tracking (outer position, inner torque)
   - Indefinite position holding after target reached

2. **Compliance**
   - Configurable soft-hold with torque ramp-down
   - Passive compliance detection (force-assisted release)

#### Safety
- Tendon tension and stability monitoring
- Safety limits (joint/mapping/motor) enforced
- Emergency stop handling
- Configurable torque/speed limits

### Communication Protocol
The system accepts serial commands from a host (PC/Raspberry Pi). See `src/commands.h` for the authoritative list. Examples:
- `STOP`, `PRETENSION`, `RELEASE`, `STARTUP_SEQUENCE`
- `SET_ZERO_CURRENT_POS`, `RECALC_OFFSET`
- `SET_PID`, `GET_PID`, `SET_PID_OUTER`, `GET_PID_OUTER`
Notes:
- Lines that start with `EVT:` are events parsed by the host — do not rename without versioned Decision.
- In integrated experiments, structured CAN diagnostics are the authoritative observability path;
  USB serial remains service-only. See `software/docs/CAN_DIAGNOSTICS_OPERATIONAL_GUIDE.md`.
- Service-only serial diagnostics include `CAN_DIAG` and `CAN_DIAG_CROSS`; the latter is a
  bench command for temporary `J4↔J5` bridging when isolating board-local `1 Mbps` behavior.

### Flash & Persistence
- Compact linear equations and limits stored in flash
- PID parameters save/load (PIDOnly data structure)

### Performance & Diagnostics
- Cycle time monitoring
- Diagnostic logs (gated via debug macros)

## Usage

### Initialization
1. Power on and hardware init
2. Load equations/limits from flash (if present)
3. Verify CAN communication with motors
4. Set zero position manually if required

### Typical Operations
1. **Calibration**
   ```
   SET_ZERO_CURRENT_POS
   ```

2. **Motion** (via CAN impedance targets)
   ```
   PRETENSION
   # Then send SET_IMPEDANCE frames via CAN (position, stiffness, damping)
   ```

3. **Recalculate Offsets**
   ```
   RECALC_OFFSET
   ```

### Maintenance
- Periodically validate mapping/equations
- Check tendon tension
- Update PID parameters as needed

## Technical Notes
- Control frequency defined by `tsample`
- Motion range: 0–110 degrees (typical Phase 0 setup)
- Typical precision: ±0.5 degrees (depends on calibration/mapping)
- Response time depends on PID configuration

## Development Standards

This firmware follows established development practices:
- **English-only** code, comments, and documentation
- **Protocol stability**: EVT messages are machine-parsable and versioned
- **Debug gating**: Logs controlled via LOG_LEVEL macros (default: INFO for release, DEBUG for debug builds)
- **Build reproducibility**: Pinned dependencies in platformio.ini
- **Safety-first**: Angle limits, mapping validation, emergency stop mechanisms
- **Documentation**: Vendor/model names included for hardware reproducibility

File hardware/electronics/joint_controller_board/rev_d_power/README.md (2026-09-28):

# rev_d_power

Power board for split Rev D architecture (`40 mm x 60 mm`).

Reference documents:
- `../docs/rev_d_architecture.md`
- `ARCHITECTURE.md`
- `COMPONENT_SELECTION.md`
- `rev_d_power_parts.kicad_sym`

Status:
- KiCad project files refreshed from `rev_d_logic` on `2026-04-13`
- redesign target remains `24V` input domain
- `.kicad_pro`, rules, symbol table, and supporting project files are aligned to the `rev_d_logic` template
- `ARCHITECTURE.md` is the authoritative design direction for the new power board
- current schematic draft now includes:
  - `RJ45` interface connector with frozen split-architecture pinout
  - `XT60` raw input: `J2`, XT60PW-F female
  - `XT60` switched output: `J4`, XT60PW-M male
  - no raw daisy-chain connector; upstream fan-out is handled by the PDU
  - input protection network with `SMCJ33A`, raw bulk capacitor, raw decoupling capacitor
  - high-side `TPS2492` hot-swap / eFuse controller driven by `SAFETY_EN`, with
    `Ilim ≈ 33.3 A` on the PCBWay first lot (`R4 = WSR31L500FEA`, 1.5 mΩ)
    and latch-off on fault (branch fuse intentionally moved off-board to
    upstream PDU — see `ARCHITECTURE.md` "External fusing")
  - `LMR36520`-based `24V -> 5V` buck draft for `+5V_FROM_POWER`
  - `TLV75533P`-based `5V -> 3V3` auxiliary LDO draft for monitor/status conditioning
  - `PWR_FLAG` markers on `24V_RAW`, `+5V_FROM_POWER`, and `GND` for clean ERC intent
  - official KiCad library symbols already adopted for:
    - `LMR36520ADDA` for the `LMR36520ADDAR` buck
    - `TLV70012_SOT23-5` as schematic base symbol for `TLV75533PDBV`
    - `Device:L` for the buck output inductor
  - first-pass analog monitors:
    - `VIN_RAW_MON` divider + RC
    - `VOUT_POST_FET_MON` divider + RC
  - first-pass status conditioning:
    - `PWRGD_N` 3.3 V pull-up
    - `FAULT_N` 3.3 V pull-up
- schematic ERC is currently at `0` errors / `0` warnings
- PCB DRC is currently at `0` violations after zone refill
- primary semiconductor selection is now frozen at architecture level:
  - high-side controller / eFuse
  - `24V -> 5V` regulator
  - `5V -> 3V3` regulator
  - input TVS
- electrical design envelope is now frozen in `ARCHITECTURE.md` for first-pass sizing:
  - worst-case local branch = HIP profile with `5` motors
  - motor sizing baseline = `24V`, `4.4 A` continuous each, `7 Nm` peak, `10:1`
  - switched branch target = `22 A` continuous, `40 A` class transient tolerance
  - logic-board rail target = `+5V_FROM_POWER @ 1 A continuous`
- first-pass primary semiconductors are now selected in `COMPONENT_SELECTION.md`:
  - `TPS2492` hot-swap / eFuse controller
  - back-to-back `BSC016N06NS` switched-path MOSFET pair
  - `LMR36520` main `24V -> 5V` buck
  - `TLV75533P` auxiliary `5V -> 3V3` LDO
  - `SMCJ33A` input TVS
- validation feedback has been folded into the design notes:
  - `TPS2492` is treated as a fixed-`50 mV` current-limit device
  - PCBWay first-lot shunt = `1.5 mOhm`, Kelvin sensed, `3W` (`WSR31L500FEA`)
  - `IMON` is intentionally not routed to RJ45 in this revision because the connector pin budget is full
  - MOSFET thermal layout must assume the `22 A` HIP envelope from day one
- local symbol library now exists for the selected active devices:
  - `rev_d_power_parts.kicad_sym`
  - project `sym-lib-table` updated to reference it
- local footprint library now freezes board-approved mechanical footprints:
  - `rev_d_power_footprints.pretty/AMASS_XT60PW-F_1x02_P7.20mm_Horizontal.kicad_mod`
  - `rev_d_power_footprints.pretty/AMASS_XT60PW-M_1x02_P7.20mm_Horizontal.kicad_mod`
  - the XT60 peg slots intentionally match the already-produced `motor_can_power_hub_rev_a` geometry (`0.6 mm x 1.7 mm` oval slot, local rotation `270`)

Bench validation:
- the PCBWay first article is bench-validated end-to-end (`2026-06`) — see `BENCH_VALIDATION_REPORT.md` for full detail
- coverage: bare-board continuity, rails, `TPS2492` hot-swap + back-to-back FET path, telemetry, `FAULT_N` handling, and closed-loop control of a real motor with safety-limit enforcement; all bring-up phases graded `PASS`
- headline numbers:
  - rails at `24V`: buck `+5V_FROM_POWER` = `5.0 V`, `3V3_AUX` LDO OK
  - `VIN_RAW_MON` = `2.18 V` exact (`24V x 8.2/90.2`), confirming divider precision
  - `TPS2492` soft-start brings `J4` to `24V` in `<` a few ms; `PWRGD_N` confirmed `ACTIVE-LOW`, `R1 = 100k` `SAFETY_EN` pulldown gives deterministic OFF default
  - closed-loop motor (joint `8`, `hip_roll_bench_right`, direct-drive): `0.08 deg` steady-state tracking error, control loop `~350 us` avg (budget `2000 us`), `0` CAN errors
  - safety layer clamps a `+40 deg` command into the conservative `[-38.5, +38.5] deg` range (`1.5 deg` inside the hard `±40 deg` limit) gracefully (WARN + clamp, no fault/E-stop)
- `PWRGD_N` / `FAULT_N` active-low polarity assumptions (written before hardware) are now confirmed on real hardware — no firmware polarity changes needed
- still pending (not done): Phase 7 high-current stress (`22 A` continuous / `~38 A` peak) and `TPS2492` real-hardware overcurrent latch-off, both needing a battery / stiff supply + external `30 A` ATO fuse + real load
- the validated first lot uses `R4 = WSR31L500FEA` (`1.5 mOhm` `3W` Kelvin shunt, `TPS2492 Ilim ≈ 33.3 A`, PCBWay-approved first-lot substitution — consistent with the body above) and `D2 = SS56B-HF`; see `BENCH_VALIDATION_REPORT.md`

Known issues (found after the June bench validation):
- **The motor rail sags or switches off when the board is touched while powered** (found 2026-08-01, reproducible). The `TPS2492` drives the pass-FET gate from a current source of a few tens of µA. Leakage of the same order into the gate node partially discharges it: the FET moves into its linear region and the switched motor rail (`J4`) sags, or turns off completely, while `VIN` stays steady and `PWRGD_N` stays asserted — so the board's own status does not flag it, and the motors lose supply mid-motion. A bare finger on the board is enough; flux residue, dust with humidity or condensation can leak the same current with nobody touching the board. Gloved or tool contact had no effect: this is a property of the µA-level gate drive, not an assembly defect.
  - never touch the power board while it is powered;
  - clean the gate area with isopropyl alcohol after soldering and keep the board dry; a conformal coating is being evaluated;
  - firmware: a motor-rail supervisor (reads `VOUT_POST_FET_MON`, declares the rail lost and stops the joint) ships with the next release.
- **The upstream `30 A` ATO branch fuse cannot clear against a current-limited 24 V converter.** A blade fuse needs several times its rating to open within seconds; typical 24 V converters limit their current (foldback, hiccup or latching shutdown) well below that. With such a source, a short on one branch collapses the whole 24 V rail instead of opening that branch's fuse. Per-branch protection is therefore electronic — the `TPS2492` current limit on each board (`~33.3 A` with the first-lot shunt); the fuse protects the wiring only when the source can deliver the fault current (e.g. a battery).

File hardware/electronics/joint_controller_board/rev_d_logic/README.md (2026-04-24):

# Joint Controller Board Rev D Logic

**Status:** Current public controller board release  
**Board size:** 60 mm x 40 mm  
**Tool baseline:** KiCad 9.0.7

## Scope

`rev_d_logic` is the controller logic board currently exposed in the public repository. It is the RP2350-based control board that interfaces with motors, CAN, safety signals, and the external encoder hub.

## Main Features

- RP2350 Pico 2 host module
- Two onboard CAN channels (`CAN1`, `CAN2`) implemented with `MCP2515 + SN65HVD230`
- RJ45 interface connector for power/safety breakout
- RJ45 encoder connector compatible with `MT6835_hub_rev_a`
- KiCad source, BOM, board setup rules, and current PCB fabrication package

## Electrical Status

Latest validation used KiCad CLI checks on the current schematic/PCB pair.

- PCB DRC: 0 violations
- PCB unconnected pads: 0
- Schematic ERC: 0 errors, 0 warnings
- Final fabrication package includes the watchdog pad-spacing fix for `MAX6369`

## Connector Summary

### J1 - Interface RJ45

1. `+5V_FROM_POWER`
2. `GND`
3. `SAFETY_EN`
4. `VIN_RAW_MON`
5. `VOUT_POST_FET_MON`
6. `PWRGD_N`
7. `FAULT_N`
8. `GND`
Shield. `GND`

### J2 - Encoder RJ45

1. `GND`
2. `ENC_SCK`
3. `ENC_MOSI`
4. `ENC_MISO`
5. `CS_ENC1`
6. `CS_ENC2`
7. `CS_ENC3`
8. `+5V`
Shield. `GND`

### CAN terminal blocks

- `CAN1`: `GND`, `CAN1_L`, `CAN1_H`
- `CAN2`: `GND`, `CAN2_L`, `CAN2_H`

## Firmware GPIO Mapping

Shared SPI:

- `GP10` -> `SCK`
- `GP11` -> `MOSI`
- `GP12` -> `MISO`

CAN:

- `GP9` -> `CAN1_CS`
- `GP13` -> `CAN1_INT`
- `GP8` -> `CAN2_CS`
- `GP14` -> `CAN2_INT`
- `GP7` -> `CAN_RST_N`

Safety / watchdog:

- `GP15` -> `WDI`
- `GP22` -> `SAFETY_EN`

Encoder:

- `GP16..GP21` -> encoder SPI lines and `CS_ENC*`

Analog monitor inputs:

- `GP26_ADC0` -> `VIN_RAW_MON`
- `GP27_ADC1` -> `VOUT_POST_FET_MON`

Digital status inputs:

- `GP5` -> `PWRGD_N`
- `GP6` -> `FAULT_N`

## Included Files

- `joint_controller_board_rev_d_logic.kicad_sch`
- `joint_controller_board_rev_d_logic.kicad_pcb`
- `joint_controller_board_rev_d_logic.kicad_pro`
- `joint_controller_board_rev_d_logic.kicad_dru`
- `joint_controller_board_rev_d_logic.step`
- `BOM_fabrication_combined.csv`
- `UCC27282D.kicad_sym`
- `sym-lib-table`
- `check_footprints.sh`
- `fabrication_release_2026-02-22_wdt_padfix/rev_d_logic_fabrication_release_2026-02-22_wdt_padfix.zip`

## Notes

- The recommended fabrication package is the `wdt_padfix` release.
- Most 3D models referenced by the PCB come from the standard KiCad 9 model libraries.

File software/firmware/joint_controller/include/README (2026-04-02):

This directory contains public headers for the `joint_controller` firmware.

Key files:
- `config_presets.h` and `JointConfig.h` — joint definitions and generated configuration surface
- `JointController.h` — top-level controller interface
- `commands.h`, `common_types.h`, `shared_data.h` — protocol and shared runtime types
- `debug.h`, `global.h`, `safety_system.h` — diagnostics, globals, and safety interfaces

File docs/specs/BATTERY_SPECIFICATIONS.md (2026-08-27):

# Battery Specifications — Alia Humanoid

> **Status**: Phase 0 Design Reference (work in progress)
> **Last Updated**: 2026-07-28
> **Note**: This document supports battery selection during design. The voltage/pack architecture
> (**10S3P Li-ion NMC pack now — 30–42 V; 48 V-ready infrastructure; 24 V buck for all motors**)
> is decided in the internal hardware-architecture roadmap (source of truth); this doc holds
> the sizing detail. The earlier 9S LiPo decision (2026-07-06) was **superseded on 2026-07-21**
> by the purchase of a UPP 36 V 10S3P NMC pack: the 40 V motor-ceiling constraint that drove 9S
> moved from the pack choice to the rail architecture, because every 24 V-class motor sits
> BEHIND the buck and never sees pack voltage. The power-distribution electronics are
> designed and marked for **30–42 V** accordingly.

---

## 1) Design Constraints

| Parameter | Value | Source |
|---|---|---|
| Robot total weight | ~25 kg (target) | project-specs-master |
| Main rail voltage | 36 V nominal (10S NMC, 30–42 V) now; 48 V-ready wiring/BMS | hardware-architecture-roadmap |
| Motor sub-rail | 24 V (buck, sized for ALL motors) | hardware-architecture-roadmap |
| Motor count (full robot) | 22 (11/leg) | MOTOR_SPECIFICATIONS |
| Motor classes | 50mm (420g, 4.4A cont.) + 40mm (183g, 1.6A cont.) | MOTOR_SPECIFICATIONS |
| Locomotion type | Walking only (no running) | Design goal |
| Drive architecture | Tendon-driven antagonistic | project-specs-master |

---

## 2) Power Consumption Estimate

### Per Subsystem

| Subsystem | Estimated Power | Notes |
|---|---|---|
| Actuators (walking ~1 km/h) | 40–80 W | 22 motors at partial load, see §3 |
| Computing (RPi5 + controllers) | 10–20 W | RPi5 ~8W, RP2350 controllers ~2W total |
| Sensors, communication | 5–10 W | IMU, encoders, CAN transceivers |
| **Total (walking)** | **~60–100 W** | Conservative estimate |
| **Total (standing idle)** | **~20–30 W** | Motors holding torque, computing active |

### Actuator Power Detail

Walking does not require all motors at full load simultaneously. Typical duty cycle:

| Phase | Active motors | Avg load per motor | Est. power |
|---|---|---|---|
| Swing phase (one leg) | 6–8 | 20–40% rated | 15–30 W |
| Stance phase (one leg) | 4–6 | 30–60% rated | 20–40 W |
| Both legs (walking cycle) | 10–14 | varies | 40–80 W |

### Tendon-Driven Efficiency Consideration

Antagonistic tendon-driven joints use 2 motors per DOF. Efficiency depends on control strategy:

| Control Mode | Efficiency vs Direct-Drive | Reason |
|---|---|---|
| One motor active (relaxed joint) | ~2× more efficient | Motor losses scale with I²R; half current → quarter losses per motor; 2 motors × 1/4 = 1/2 total losses |
| Moderate co-contraction | Comparable | Both motors active, partially cancelling each other |
| High co-contraction (rigid joint) | Less efficient | Energy wasted in internal opposition |

> **Design implication**: Minimizing co-contraction through intelligent control is critical for battery life. A good controller should use co-contraction only when joint stiffness is needed (stance phase, perturbation response).

---

## 3) Battery Sizing

### Options by Autonomy Target

| Autonomy | Energy Required | Battery Weight | Approx. Dimensions | % of Robot Weight |
|---|---|---|---|---|
| 30 min | 30–50 Wh | 0.2–0.3 kg | ~100×60×25 mm | ~1% |
| **1 hour** | **60–100 Wh** | **0.4–0.7 kg** | **~130×80×30 mm** | **~2–3%** |
| **1.5 hours** | **100–150 Wh** | **0.7–1.0 kg** | **~150×90×35 mm** | **~3–4%** |
| 2 hours | 120–200 Wh | 0.8–1.3 kg | ~150×100×40 mm | ~4–5% |

> **Recommended target**: 100–150 Wh (~1–1.5 hours walking). This keeps battery weight under 4% of total robot weight while providing meaningful operational time.

> **Space planning**: Current estimates cover lower body only (22 motors; 27 with the pelvis). Adding the upper limbs (2 arms + head) scales the two budgets **differently**: motor **count / CAN / compute ≈ 2×** (arms are DOF-rich), but **power ≈ 1.5×** (arms don't bear weight + reduced-power motors → upper ≈ 50 % of the legs). The torso battery compartment should still be sized for **~200–300 Wh** to cover full-body operation without redesigning the frame (internal roadmap: Upper-body reserve).

### Pack Configuration — 10S3P Li-ion NMC (supersedes 9S, 2026-07-21)

| Configuration | Nominal Voltage | Range (cutoff–full) | Pack |
|---|---|---|---|
| **10S3P NMC** | **36 V** | **30 V – 42 V** | UPP 36 V pack with integrated BMS (purchased) |

> **Why the change from 9S:** 9S existed to keep full-charge voltage under the MG5010E-i10
> 40 V ceiling. With the final architecture every 24 V-class motor is fed from the buck and
> **never sees pack voltage**, so the ceiling constraint moved from the pack to the rail
> design — freeing the choice to a commercial 10S NMC pack with integrated BMS. All power
> electronics (pack disconnect, fuse voltage class, DC-DC input stage) are
> rated for the full **30–42 V** window; the 30 V documented floor equals the pack's 3.0 V/cell
> cutoff. Wiring, connectors and the buck input remain **48 V-ready**, but the move to 13S
> (54.6 V full) is **not** a pack swap: it exceeds the input ceiling of the current DC-DC stage and the
> overvoltage protection window of the pack-disconnect electronics —
> **the power-distribution boards need a revision for 13S**.
> Bench gate: verify precharge/UVLO behaviour at the true end-of-discharge voltage.

<details><summary>Superseded: 9S LiPo sizing (2026-07-06)</summary>

| Configuration | Nominal Voltage | Max (full) | Capacity for ~100 Wh | Capacity for ~150 Wh |
|---|---|---|---|---|
| 9S | 33.3 V | 37.8 V | ~3000 mAh | ~4500 mAh |

</details>

---

## 4) Comparable Robots

| Robot | Weight | Battery | Autonomy | Wh/kg ratio | Notes |
|---|---|---|---|---|---|
| NAO (Aldebaran) | 5.4 kg | 48 Wh | ~90 min | 8.9 | Small, electric servo |
| Unitree G1 | 35 kg | ~450 Wh | ~2 h | 12.9 | Running capable |
| Unitree H1 | 47 kg | ~864 Wh | ~2 h | 18.4 | High-performance |
| **Alia (target)** | **25 kg** | **100–150 Wh** | **~1–1.5 h** | **4–6** | **Walking only, tendon-driven** |

Alia's lower Wh/kg ratio is justified by:
- Walking only (no running = much lower peak power)
- Tendon-driven efficiency (lower motor currents)
- Lightweight frame (PA12 MJF, not metal)
- No high-performance dynamic maneuvers

---

## 5) Physical Placement

### Location: Torso (preferred)

| Consideration | Rationale |
|---|---|
| Center of mass | Torso keeps CoM high and centered, beneficial for walking stability |
| Wire routing | Short runs to motor drivers, minimal voltage drop |
| Accessibility | Easy battery swap for testing |
| Thermal | Away from leg motors, natural ventilation |

### Mounting

| Aspect | Description |
|---|---|
| Method | Removable tray or Velcro strap (Phase 0) |
| Connector | XT60 or XT90 (standard for LiPo at this current) |
| Protection | Low-voltage cutoff via BMS or firmware |

---

## 6) Safety

| Risk | Mitigation |
|---|---|
| Over-discharge | BMS with per-cell monitoring, firmware low-voltage alarm |
| Over-current | Fuse or PTC on main power line |
| Physical damage | Battery enclosed in torso shell, no external exposure |
| Charging | External balance charger only, not integrated (Phase 0) |
| Thermal runaway | LiPo fire-safe bag for storage; battery compartment ventilation |

---

## 7) Open Questions

- [x] ~~6S vs 7S vs 9S~~ → **RESOLVED: 10S3P NMC** (2026-07-21 supersession; the 40 V motor ceiling moved to the rail architecture — 24 V motors sit behind the buck). MG4005 ankles on the 24 V buck.
- [ ] Peak current draw during walking (measure on prototype) — **the gate for final capacity/C-rate**
- [ ] Co-contraction energy cost (measure idle vs walking power delta)
- [ ] Battery placement effect on CoM (simulation needed)
- [ ] Integrated BMS vs external BMS

---

## 8) Next Steps

1. Measure actual power consumption on lower-body prototype (tethered 24V PSU) — incl. co-contraction idle draw
2. Determine peak vs average current profiles during walking
3. ~~Select the pack~~ → **done: UPP 10S3P NMC purchased** (see §3); size any second pack from the measurement above
4. ~~Source candidate packs~~ → done (UPP pack in hand); torso fit check at integration
5. Design the power-management electronics + battery tray CAD — after the current measurement

---

**Document Control**:
- Version: 0.1
- Source: Design discussion, MOTOR_SPECIFICATIONS cross-reference
- Next Review: After lower-body power measurement

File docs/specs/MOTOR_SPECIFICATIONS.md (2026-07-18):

# Motor Specifications — Alia Humanoid

> **Status**: Phase 0 Reference  
> **Last Updated**: 2025-12-16  
> **Note**: Brand names disclosed in Phase 1 BOM release

---

## 1) Motor Classes

Alia uses two classes of **Quasi-Direct Drive (QDD)** motors with integrated planetary gearbox.

| Class | Frame Size | Application |
|---|---|---|
| **50mm Class** | ~50mm diameter | High-torque joints (plantarflexion, knee, hip/pelvis tendon pairs) |
| **40mm Class** | ~40mm diameter | Lower-torque joints (dorsiflexion, inversion, eversion) |
| **60mm Class** | ~60mm diameter | **Direct-drive roll axes** (hip ×2 + pelvis ×1) — upsized, 48 V |

---

## 2) 50mm Class Motor

### Specifications

| Parameter | Value | Notes |
|---|---|---|
| **Continuous Torque** | 4 Nm | Post-reduction |
| **Peak Torque** | 7 Nm | Post-reduction |
| Continuous Current | 4.4 A | — |
| Rated Speed | 235 RPM | Post-reduction |
| Voltage | 24V DC | Nominal |
| Reduction Ratio | **1:10** | Integrated planetary gearbox |
| Backlash | ≤10 arcmin | — |
| **Weight** | 420g | — |
| Efficiency Class | IE 2 | — |
| Encoder | 18-bit absolute | Magnetic |
| Communication | CAN bus / RS485 | — |
| Frame Diameter | ~50 mm | Approximate |

### Application

| Joint | DOF | Quantity |
|---|-----|---|
| Ankle | Plantarflexion | 1 |
| Knee | Extension | 1 |
| Knee | Flexion | 1 |
| Hip | All directions | 2+ |

---

## 3) 40mm Class Motor

### Specifications

| Parameter | Value | Notes |
|---|---|---|
| **Continuous Torque** | 1 Nm | Post-reduction |
| **Peak Torque** | 2.5 Nm | Post-reduction |
| Continuous Current | 1.6 A | — |
| Rated Speed | 253 RPM | Post-reduction |
| Voltage | 24V DC | Nominal |
| Reduction Ratio | **1:10** | Integrated planetary gearbox |
| Backlash | ≤10 arcmin | — |
| **Weight** | 183g | — |
| Efficiency Class | IE 3 | Higher efficiency |
| Encoder | 18-bit absolute | Magnetic |
| Communication | CAN bus / RS485 | — |
| Bearing Load | 1000N | Axial/radial combined |
| Frame Diameter | ~40 mm | Approximate |

### Application

| Joint | DOF | Quantity |
|---|-----|---|
| Ankle | Dorsiflexion | 1 |
| Ankle | Inversion | 1 |
| Ankle | Eversion | 1 |

---

## 3b) 60mm Class Motor — roll-axis upsize (LKMTECH MG6012E-i8-V2)

The roll axes are **direct-drive** (no tendon reduction → no ~8× torque multiplication), so the
50 mm motor was torque-starved: the mjlab walking policy needs ~8.5 N·m peak in nominal gait and
~18 N·m under 0.4 m/s disturbance recovery, but the direct MG5010 caps at 7 N·m (20 % time saturated
under pushes). Upsized to the **LKMTECH MG6012E-i8-V2** — **16 N·m peak at essentially no mass
penalty** (430 g vs 420 g), and **48 V-native** (first load on the main rail; the 24 V motors stay on
the buck).

### Specifications

| Parameter | Value | Notes |
|---|---|---|
| **Continuous Torque** | 6 Nm | Post-reduction |
| **Peak Torque** | 16 Nm | ~2.3× the MG5010 (7 Nm); covers gait 1.9× + most of the disturbance envelope |
| Rated Current | 3.5 A | @48 V |
| Max Speed | 310 RPM | Post-reduction |
| Voltage | **48V** | 48 V-native (24 V motors stay on the buck) |
| Reduction Ratio | **1:8** | more backdrivable than the 1:10 it replaces |
| **Weight** | 430g | ≈ MG5010 (420 g) → no mass penalty |
| Encoder | 18-bit motor + 14-bit reducer | Magnetic, dual |
| Communication | CAN / RS485 | same LKMTECH family (tooling/firmware reuse) |
| Frame Diameter | ~60 mm | Approximate |
| Approx. price | ~$290 | aifitlab (2026-07-06) |

> **Procurement (2026-07-06):** 3× ordered (2 hip + pelvis roll). Imported as a **private EU buyer**
> (no VAT number → the Alibaba "EU tax exemption" is B2B-only, not applicable). Order > €150 → normal
> import rules (NOT the ≤ €150 IOSS / new €3-flat-duty regime): budget **~22–25 % on top** on delivery
> = Italy import VAT 22 % + possible small HS-8501 duty + courier clearance fee. Confirm lead time with
> the seller (bare-chip channels run long; this is a finished module so likely shorter).

### Application

| Joint | DOF | Quantity |
|---|-----|---|
| Hip | Roll (axial, direct-drive) | 2 (one per leg) |
| Pelvis | Roll (axial, direct-drive) | 1 |

> Caveat: 16 N·m is ~10 % under the extreme ~18-20 N·m disturbance peak → slight clipping only on the
> hardest pushes. Chasing the last few N·m means an 80 mm motor (MG8016, ~0.8-1 kg) whose mass penalty
> high on the hip/pelvis worsens the very disturbance dynamics — so 16 N·m @ 430 g is the sweet spot.

---

## 4) Common Characteristics

### Quasi-Direct Drive (QDD) Architecture

| Feature | Benefit |
|---|---|
| Low reduction ratio (1:10) | High backdrivability |
| Integrated gearbox | Compact package |
| Magnetic encoder | Absolute position at startup |
| CAN bus interface | Multi-motor networking |

### Mounting

| Aspect | Description |
|---|---|
| Method | Friction fit on outer circumference |
| Benefit | Allows motor brand substitution with CAD adaptation |
| Material | PA12 nylon motor housing |

---

## 5) Electrical Integration

### Power

| Parameter | Value |
|---|---|
| Bus Voltage | 24V DC |
| Recommended PSU | 24V, 10A minimum (per leg) |
| Peak Current (4 motors) | ~15A (ankle assembly) |

### Communication

| Parameter | Value |
|---|---|
| Protocol | CAN 2.0B |
| Baud Rate | 1 Mbps |
| Addressing | Per-motor unique ID |
| Topology | Daisy-chain |

---

## 6) Thermal Considerations

### Operating Limits

| Parameter | 50mm Class | 40mm Class |
|---|---|---|
| Continuous operation | 100% rated torque | 100% rated torque |
| Duty cycle at peak | [TBD] | [TBD] |
| Ambient temp max | [TBD] | [TBD] |

### Design Margin

- Continuous operation at **50-75% motor capacity**
- Peak ratings for transient phases only (push-off, heel strike)
- Thermal safety ensured by conservative utilization

---

## 7) Motor Count Summary

### Current Robot Configuration

| Joint | 50mm (MG5010) | 40mm (MG4005) | 60mm (MG6012, roll) | Total |
|---|---|---|---|---|
| Ankle (per leg) | 1 | 3 | 0 | 4 |
| Knee (per leg) | 2 | 0 | 0 | 2 |
| Hip (per leg) | 4 | 0 | 1 (roll) | 5 |
| **Per Leg** | **7** | **3** | **1** | **11** |
| Pelvis (×1, central) | 4 | 0 | 1 (roll) | 5 |
| **Full Robot** (2 legs + pelvis) | **18** | **6** | **3** | **27** |

> **27 motors** = 2 legs (11 each) + **pelvis** (5, same topology as hip: pitch+yaw tendon pairs +
> single roll). **Roll axes are direct-drive** (no tendon reduction → torque-starved), so all **3
> roll motors (2 hip + 1 pelvis) are UPSIZED to the LKMTECH MG6012E-i8-V2** (60 mm, **48 V**, 6/16 N·m)
> — see §3b. Everything else stays MG5010E-i10 (24 V) / MG4005E-i10 (24 V). The pelvis carries the
> electronics/battery bay + upper mass (internal hardware-architecture roadmap).

### Weight Budget

| Assembly | Motor Weight |
|---|---|
| Ankle | 969g (1×420g + 3×183g) |
| Knee | 840g (2×420g) |
| Hip | 2110g (4×420g + 1×430g roll) |
| **Per Leg** | **~3.9 kg** |
| Pelvis | 2110g (4×420g + 1×430g roll) |
| **Full Robot** (2 legs + pelvis) | **~9.9 kg** (motors only) |

---

## 8) Phase 1 Disclosure

In Phase 1, the following will be released:
- Manufacturer name
- Exact model numbers
- Datasheet links
- Recommended drive electronics
- Alternative compatible motors

---

**Document Control**:
- Version: 1.0
- Source: project-specs-master.md (sections 1.2 Motor Specifications)
- Next Review: Phase 1 release

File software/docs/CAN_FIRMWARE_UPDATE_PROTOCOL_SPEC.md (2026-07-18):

# CAN Firmware Update Protocol Specification

> **License:** this specification is released under the MIT License (unlike the GPLv3
> firmware/host code) so third-party tools can implement it without copyleft obligations.

**Status:** Draft Technical Specification
**Date:** 2026-04-08
**Implementation state:** Flash map regions, slot linker targets, metadata
record helpers, boot-time metadata initialization/reconciliation, metadata
transition helpers, inactive-slot writer primitives, a boot/update selector,
build-time artifact manifests, Host CAN command bindings, and a host-side
end-to-end updater now exist in code; rollback after deliberate non-confirmation,
interrupted-update resume, corrupted-image rejection, and the planned single-board
power-loss campaigns are validated on hardware
**Scope:** Safe firmware update over Host CAN for RP2350 joint controllers

---

## 1. Purpose

This document defines the concrete protocol and boot behavior for future
firmware reflashing over Host CAN.

It is intentionally stricter than the high-level design notes:
- fixed CAN IDs
- fixed frame payloads
- fixed slot model
- explicit update and boot state machines

This protocol is for the **Host CAN** path only.

Practical status on `2026-04-08`:
- the complete single-board Host-CAN update path was validated on real hardware
- the validated path wrote a `277700`-byte `slot B` image and completed:
  - `VERIFY_OK`
  - `ACTIVATE_OK`
  - reboot into candidate
  - `CANDIDATE_BOOT_OK`
  - `CONFIRM_OK`
  - `MAINTENANCE_EXITED`
- final observed runtime state was `active_slot=2`, `pending_slot=0`,
  `boot_state=BOOT_STABLE`
- rollback was then validated on the same board by:
  - writing a `slot A` candidate
  - rebooting into that candidate
  - intentionally skipping `CONFIRM_UPDATE`
  - forcing a second reboot
  - observing automatic return to stable `slot B`
- final observed rollback state was `active_slot=2`, `pending_slot=0`,
  `boot_state=BOOT_STABLE`
- interrupted-update resume was then validated by:
  - stopping the host after committed page `32/1087`
  - reconnecting while the controller remained in `BOOT_RECEIVING`
  - resuming at `page 33/1087` from `FW_UPDATE_PROGRESS.next_page_index`
  - completing verify, activate, candidate boot, confirm, and maintenance exit
- corrupted-image rejection was then validated by:
  - intentionally flipping transmitted byte offset `12345`
  - observing `IMAGE_CRC_MISMATCH` on `VERIFY_UPDATE`
  - aborting the failed candidate and returning to the previous stable slot
- the planned single-board power-loss campaign was then validated on
  `2026-04-08`:
  - power loss during `BOOT_RECEIVING` returned the board in
    `BOOT_RECEIVING + maintenance`, and `cleanup-session` restored the previous
    stable slot
  - power loss after `VERIFY_OK` but before `ACTIVATE_SLOT` returned the board
    in `BOOT_VERIFIED + maintenance`, and `cleanup-session` restored the
    previous stable slot
  - power loss during the first boot of a pending candidate caused automatic
    rollback to the previous stable slot; the board then required only a final
    maintenance exit for cleanup
- final board state was restored to `active_slot=2`, `pending_slot=0`,
  `boot_state=BOOT_STABLE`

Power-loss execution guide:
- `software/docs/CAN_POWER_LOSS_VALIDATION_RUNBOOK.md`

---

## 2. Transport Assumptions

The baseline Alia architecture uses:
- one Host CAN channel per joint controller
- one controller per Host CAN channel
- Jetson or host updater connected to that dedicated channel

Implications:
- update traffic is **not** designed as a broadcast fleet update
- the target board is selected by host channel assignment first
- `board_uid` is still checked during session setup to prevent wrong-target
  updates caused by wiring mistakes or misidentified hardware

Real transport note:
- on the current `Jetson/SLCAN -> MCP2515` path, the host must apply explicit
  pacing between update frames
- real hardware initially failed with:
  - `INVALID_STATE` when `BEGIN_UPDATE + META_A + META_B` were sent as a burst
  - `FRAG_INDEX_MISMATCH` when `PAGE_BEGIN` was followed too aggressively by
    early fragments
- the current validated host pacing is:
  - `10 ms` between `BEGIN_UPDATE`, `META_A`, and `META_B`
  - `10 ms` between `PAGE_BEGIN` and fragment `0`
  - `5 ms` between page fragments

This pacing is an implementation requirement for the current transport, not just
an optimization.

If a future shared service bus is introduced, this protocol must keep the same
session semantics, but stricter UID filtering will be required on every session.

---

## 3. Final Flash Layout Candidate

The current top-of-flash NVM should remain stable. The CAN update design should
add slot metadata below it, not move it again.

Recommended `4 MB` flash map:

```text
0x000000 - 0x01FFFF  Boot / update region         (128 KB)
0x020000 - 0x11FFFF  App slot A                   (1 MB)
0x120000 - 0x21FFFF  App slot B                   (1 MB)
0x220000 - 0x3F7FFF  Reserved / service growth
0x3F8000 - 0x3F9FFF  Update metadata journal      (8 KB, 2 sectors)
0x3FA000 - 0x3FEFFF  Persistent NVM               (20 KB, current layout)
0x3FF000 - 0x3FFFFF  Framework-reserved tail      (4 KB)
```

Properties:
- current persistent records remain at their new top-of-flash addresses
- update metadata gets its own dedicated two-sector ping-pong journal
- both application slots are far below persistent data
- slot erase/program operations cannot overlap persistent NVM by design

---

## 4. Component Responsibilities

### 4.1 Boot / update region

Responsible for:
- selecting slot A or slot B at boot
- honoring `pending_slot`
- decrementing boot-attempt budget for candidate images
- rolling back to the last confirmed slot if candidate boot fails

### 4.2 Active application

Responsible for:
- entering maintenance mode
- receiving CAN update commands
- writing the inactive slot only
- verifying the candidate image before activation
- booting in provisional maintenance mode after activation
- sending candidate-boot status to the host

### 4.3 Host updater

Responsible for:
- checking board identity before update
- forcing maintenance mode
- sending image metadata
- streaming page data
- requesting verify / activate / reboot
- confirming the candidate image only after it boots correctly

---

## 5. Metadata Model

The update metadata region should store journaled records, not a single mutable
struct overwritten in place.

Current code direction:
- one metadata record occupies exactly one `256`-byte flash page
- each `4 KB` metadata sector therefore holds `16` journal entries
- the active metadata journal now spans **two sectors**
- records are appended until the active sector is full, then the latest record
  is written into the alternate sector before the stale sector is erased

Recommended record fields:

```c
struct UpdateMetadataRecord {
    uint32_t magic;
    uint16_t version;
    uint16_t record_size;
    uint32_t record_seq;

    uint8_t  active_slot;          // 1=A, 2=B
    uint8_t  pending_slot;         // 0=none, 1=A, 2=B
    uint8_t  boot_state;           // enum BootState
    uint8_t  attempts_remaining;

    uint32_t slot_a_size;
    uint32_t slot_a_crc32;
    uint32_t slot_b_size;
    uint32_t slot_b_crc32;

    uint32_t candidate_size;
    uint32_t candidate_crc32;
    uint32_t board_uid_crc32;
    uint16_t protocol_major;
    uint16_t protocol_minor;

    uint32_t flags;
    uint32_t header_crc32;
    uint8_t  reserved[200];
};
```

Recommended policy:
- append a new metadata record for every state transition
- compact by ping-pong sector swap only when the active sector is full
- on boot, load the latest valid record by `record_seq`

This avoids torn-state failure from a single partially rewritten metadata block
and removes the destructive erase-before-write window from the previous
single-sector design.

---

## 6. Slot and Boot States

### 6.1 Slot values

- `0` = none
- `1` = slot A
- `2` = slot B

### 6.2 BootState enum

- `0` = `BOOT_STABLE`
- `1` = `BOOT_MAINTENANCE`
- `2` = `BOOT_RECEIVING`
- `3` = `BOOT_VERIFIED`
- `4` = `BOOT_PENDING_TEST`
- `5` = `BOOT_CANDIDATE_RUNNING`
- `6` = `BOOT_ROLLBACK_REQUIRED`
- `7` = `BOOT_ROLLED_BACK`

Meaning:
- `BOOT_STABLE`: normal confirmed application
- `BOOT_PENDING_TEST`: next reboot must try `pending_slot`
- `BOOT_CANDIDATE_RUNNING`: candidate app booted but is not confirmed yet
- `BOOT_ROLLBACK_REQUIRED`: bootloader must return to the last stable slot

---

## 7. CAN ID Allocation

These IDs are now active in the current firmware/host implementation for the
full single-board activation flow.

### 7.1 Host → Controller

| ID | Name | Purpose |
|----|---|---|
| `0x020` | `FW_UPDATE_CTRL` | Session control, maintenance, verify, activate, confirm, reboot |
| `0x021` | `FW_UPDATE_META_A` | Image metadata A |
| `0x022` | `FW_UPDATE_META_B` | Image metadata B / page begin |
| `0x023` | `FW_UPDATE_DATA` | Page fragment data |

### 7.2 Controller → Host

| ID | Name | Purpose |
|----|---|---|
| `0x560 + joint_id` | `FW_UPDATE_STATUS` | Ack, errors, state transitions |
| `0x570 + joint_id` | `FW_UPDATE_UID` | Full 8-byte board UID |
| `0x580 + joint_id` | `FW_UPDATE_INFO` | Slot, version, flags, attempts remaining |
| `0x590 + joint_id` | `FW_UPDATE_PROGRESS` | Next expected page and receive progress |

Rationale:
- command IDs stay in the existing reserved high-priority range after `0x01E`
- status IDs stay above the current operational feedback and diagnostics ranges
- they intentionally avoid collisions with:
  - `0x4A0..0x4F0` operational feedback
  - `0x510..0x550` CAN-first diagnostics

---

## 8. Frame Formats

All multi-byte fields are little-endian.

### 8.1 `0x020` `FW_UPDATE_CTRL`

```text
Byte 0: opcode
Byte 1: arg0
Byte 2: arg1
Byte 3: arg2
Byte 4: arg3
Byte 5: arg4
Byte 6: arg5
Byte 7: arg6
```

#### Opcodes

- `0x01` `GET_UPDATE_INFO`
- `0x02` `ENTER_MAINTENANCE`
- `0x03` `EXIT_MAINTENANCE`
- `0x04` `BEGIN_UPDATE`
- `0x05` `END_UPDATE`
- `0x06` `VERIFY_UPDATE`
- `0x07` `ACTIVATE_SLOT`
- `0x08` `CONFIRM_UPDATE`
- `0x09` `ABORT_UPDATE`
- `0x0A` `REBOOT`

#### Opcode payload rules

`GET_UPDATE_INFO`
- all remaining bytes `0x00`

`ENTER_MAINTENANCE`
- `arg0` flags
- bit `0`: require movement idle before acceptance
- bit `1`: reject if startup sequence active
- bit `2`: stay in maintenance after reboot

`BEGIN_UPDATE`
- `arg0` target slot (`1=A`, `2=B`)
- `arg1` image format (`1=raw bin`)
- `arg2` fw major
- `arg3` fw minor
- `arg4` fw patch
- `arg5` options
- bit `0`: allow same-version update
- bit `1`: candidate boots in maintenance mode
- `arg6` reserved

`VERIFY_UPDATE`
- `arg0` target slot

`ACTIVATE_SLOT`
- `arg0` target slot
- `arg1` boot-attempt budget (`1..3`)

`CONFIRM_UPDATE`
- `arg0` slot being confirmed

`REBOOT`
- `arg0` reboot mode (`0=normal`, `1=stay in maintenance`)

### 8.2 `0x021` `FW_UPDATE_META_A`

Sent immediately after `BEGIN_UPDATE`.

```text
Byte 0-3: image_size_bytes   (uint32)
Byte 4-7: image_crc32        (uint32)
```

### 8.3 `0x022` `FW_UPDATE_META_B`

Sent immediately after `FW_UPDATE_META_A`.

```text
Byte 0-3: board_uid_crc32    (uint32)
Byte 4-5: protocol_major/minor
Byte 6-7: reserved
```

Controller acceptance rule:
- `board_uid_crc32` must match the local board
- if it does not match, the board rejects the session before any slot erase

### 8.4 `0x022` `FW_UPDATE_PAGE_BEGIN`

Reuses `0x022` after the session is open.

```text
Byte 0-2: page_index         (uint24)
Byte 3:   page_seq           (uint8)
Byte 4:   page_len_mod256    (0 means 256)
Byte 5:   flags              (bit0 = final page)
Byte 6-7: page_crc16         (uint16)
```

Rules:
- page size is fixed at `256` bytes in flash
- `page_index` addresses the inactive slot relative to its base
- actual page byte count is:
  - `256` if `page_len_mod256 == 0`
  - otherwise `page_len_mod256`
- only the final page may be shorter than `256`

### 8.5 `0x023` `FW_UPDATE_DATA`

```text
Byte 0:   page_seq
Byte 1:   frag_index
Byte 2-7: data[6]
```

Rules:
- controller accepts data only for the current open page
- fragments must arrive in order starting from `frag_index = 0`
- a `256`-byte page requires `43` data frames (`42 * 6 + 4`)
- controller buffers one full page in RAM, validates `page_crc16`, then writes
  that page into the inactive slot

This page-based transport keeps `6` useful data bytes per CAN frame while still
supporting slot sizes larger than `393210` bytes.

### 8.6 `0x560 + joint_id` `FW_UPDATE_STATUS`

```text
Byte 0: event_code
Byte 1: boot_state
Byte 2: active_slot
Byte 3: pending_slot
Byte 4: error_code
Byte 5: flags
Byte 6-7: value
```

`value` meaning depends on `event_code`.

Recommended `event_code` values:
- `0x01` `INFO_READY`
- `0x02` `MAINTENANCE_ENTERED`
- `0x03` `MAINTENANCE_EXITED`
- `0x04` `BEGIN_ACCEPTED`
- `0x05` `PAGE_COMMITTED`
- `0x06` `VERIFY_OK`
- `0x07` `ACTIVATE_OK`
- `0x08` `CANDIDATE_BOOT_OK`
- `0x09` `CONFIRM_OK`
- `0x0A` `ROLLBACK_OCCURRED`
- `0x40` `ERROR`

Recommended `error_code` values:
- `0x00` none
- `0x01` busy
- `0x02` invalid_state
- `0x03` uid_mismatch
- `0x04` invalid_slot
- `0x05` update_not_started
- `0x06` page_seq_mismatch
- `0x07` frag_index_mismatch
- `0x08` page_crc_mismatch
- `0x09` slot_bounds_error
- `0x0A` image_crc_mismatch
- `0x0B` verify_failed
- `0x0C` confirmation_timeout
- `0x0D` candidate_boot_failed

### 8.7 `0x570 + joint_id` `FW_UPDATE_UID`

```text
Byte 0-7: full board UID (8 bytes)
```

### 8.8 `0x580 + joint_id` `FW_UPDATE_INFO`

```text
Byte 0: active_slot
Byte 1: pending_slot
Byte 2: boot_state
Byte 3: attempts_remaining
Byte 4: fw_major
Byte 5: fw_minor
Byte 6: fw_patch
Byte 7: flags
```

`flags`:
- bit `0`: maintenance active
- bit `1`: update in progress
- bit `2`: candidate awaiting confirmation

### 8.9 `0x590 + joint_id` `FW_UPDATE_PROGRESS`

```text
Byte 0-2: next_page_index    (uint24)
Byte 3:   last_page_seq
Byte 4:   last_frag_index
Byte 5:   boot_state
Byte 6-7: reserved
```

This frame is used for:
- `GET_UPDATE_INFO` responses
- progress updates every N committed pages
- host-side recovery after interrupted transfer

---

## 9. Update Session State Machine

### 9.1 Normal path

1. host sends `GET_UPDATE_INFO`
2. controller replies with `FW_UPDATE_UID` and `FW_UPDATE_INFO`
3. host validates expected board UID
4. host sends `ENTER_MAINTENANCE`
5. controller enters maintenance and sends `MAINTENANCE_ENTERED`
6. host sends `BEGIN_UPDATE`
7. host sends `FW_UPDATE_META_A`
8. host sends `FW_UPDATE_META_B`
9. controller validates metadata, erases the inactive slot, sends `BEGIN_ACCEPTED`
10. host streams page data:
   - `FW_UPDATE_PAGE_BEGIN`
   - `FW_UPDATE_DATA` fragments
11. controller commits each validated page and periodically emits `FW_UPDATE_PROGRESS`
12. host sends `END_UPDATE`
13. host sends `VERIFY_UPDATE`
14. controller verifies whole-slot image and sends `VERIFY_OK`
15. host sends `ACTIVATE_SLOT`
16. controller records `pending_slot` and sends `ACTIVATE_OK`
17. host sends `REBOOT`
18. boot region starts candidate slot in provisional maintenance mode
19. candidate app reaches stable startup and emits `CANDIDATE_BOOT_OK`
20. host performs basic health checks
21. host sends `CONFIRM_UPDATE`
22. controller commits candidate as stable and sends `CONFIRM_OK`
23. host may optionally send `EXIT_MAINTENANCE`

Validated hardware outcome on `2026-04-07`:
- this exact sequence completed on `hip_roll_bench_right`
- the controller returned to `active_slot=2`, `pending_slot=0`,
  `boot_state=BOOT_STABLE`

### 9.2 Abort path

If the host sends `ABORT_UPDATE` before `ACTIVATE_SLOT`:
- controller stops accepting page data
- current stable slot remains unchanged
- incomplete candidate data may remain in the inactive slot but is not bootable

---

## 10. Boot and Rollback State Machine

### 10.1 Activation behavior

After `ACTIVATE_SLOT`:
- `pending_slot` is set
- `boot_state = BOOT_PENDING_TEST`
- `attempts_remaining` is set from `ACTIVATE_SLOT`

### 10.2 Bootloader behavior

On reset:

1. load latest metadata record
2. if `boot_state == BOOT_PENDING_TEST`:
   - decrement `attempts_remaining`
   - if `attempts_remaining == 0`, set `BOOT_ROLLBACK_REQUIRED`
   - otherwise jump to `pending_slot`
3. if `boot_state == BOOT_ROLLBACK_REQUIRED`:
   - clear `pending_slot`
   - restore last stable `active_slot`
   - set `BOOT_ROLLED_BACK`
   - boot stable slot
4. if `boot_state == BOOT_STABLE`:
   - boot `active_slot`

### 10.3 Candidate image behavior

The candidate application must:
- boot in maintenance mode
- reject motion and calibration writes
- perform startup self-checks
- emit `CANDIDATE_BOOT_OK` only after reaching a stable ready state

It must **not** mark itself stable automatically.

Final stabilization requires host-side `CONFIRM_UPDATE`.

### 10.4 Confirmation timeout policy

If the candidate image boots but never receives `CONFIRM_UPDATE`:
- it remains provisional
- if power is lost or the board resets before confirmation, the next boot rolls
  back to the previously stable slot

This is intentional. A candidate image must prove both:
- it can boot
- the host accepts it

---

## 11. Failure Semantics

### 11.1 Wrong target

If `board_uid_crc32` does not match:
- controller rejects `BEGIN_UPDATE`
- no slot erase occurs

### 11.2 Transport corruption

If page CRC fails:
- controller rejects the page
- controller emits `ERROR` with `page_crc_mismatch`
- host resends that page only

### 11.3 Interrupted transfer

If power is lost during receive:
- current stable slot is still bootable
- incomplete inactive slot image is ignored
- host restarts from `GET_UPDATE_INFO`

### 11.4 Candidate boot failure

If the candidate slot cannot reach `CANDIDATE_BOOT_OK`:
- next boot returns to the last stable slot
- controller emits `ROLLBACK_OCCURRED` after recovery

---

## 12. Practical Notes

### 12.1 Why page-based transfer

This protocol uses:
- one page-begin frame
- multiple `6`-byte fragment frames per `256`-byte page

Benefits:
- preserves good CAN payload efficiency
- supports large slot sizes
- aligns naturally with flash program page handling
- localizes retry to one page, not the entire image

### 12.2 Why host confirmation is required

An app that merely jumps to `main()` is not yet a safe update.

For Alia, the new image should remain provisional until the host confirms:
- the board boots
- the board reports the expected version
- the board stays in maintenance mode
- the board is still reachable over Host CAN

---

## 13. Recommended Next Implementation Step

Before writing any transport code, freeze these two artifacts in code:

1. final flash map with:
   - boot/update region
   - slot A
   - slot B
   - update metadata journal
   - persistent NVM
2. update metadata struct and boot-state enum

Current code status against that requirement:

1. `flash_map.h` now freezes the target regions
2. metadata record types and boot-state enums now exist in firmware
3. slot builds now emit `firmware_manifest.json` with:
   - link target
   - flash XIP base
   - slot size
   - image size
   - image CRC32
4. runtime firmware now initializes missing metadata and can promote
   `pending_test -> candidate_running` when a slot-linked image boots
5. firmware-side transition helpers now exist for:
   - maintenance enter/exit
   - abort
   - activate
   - confirm
   - rollback-required / rollback-finalized
6. inactive-slot writer primitives now exist for:
   - begin/update session metadata
   - inactive-slot erase
   - ordered page writes with CRC16 validation
   - final image CRC32 verification

That means the next missing implementation is no longer "define the layout", but
"bind these primitives to real CAN commands and make boot/update code consume
them safely."

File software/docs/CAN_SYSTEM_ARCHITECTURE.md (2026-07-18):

# CAN System Architecture for Alia Humanoid Robot

> **License:** this specification is released under the MIT License (unlike the GPLv3
> firmware/host code) so third-party tools can implement it without copyleft obligations.

**Document Version:** 2.4
**Date:** 2026-06-30
**Status:** Design Specification (v1.0 host↔controller freeze subset added)
**Authors:** Alia Robotics Team

**Changelog v2.4 (D067/DOF1 hardening):**
- **IMPEDANCE_CTRL extended**: documents adaptive-HOLD mask and diagnostic Loop2 actuation subcommands
- **FAULT_SNAPSHOT_CTRL added**: documents host retrieval control path at CAN ID `0x01F`
- **CAN ID table corrected**: reserved range now starts at `0x020`

**Changelog v2.3 (D034):**
- **Protocol v1.0 freeze subset added**: documents the bench-validated host↔controller baseline for `KNEE_RIGHT` and `ANKLE_RIGHT`
- **Startup / recovery policy frozen**: nominal startup, already-ready resume, and same-session post-`E-stop` recovery are now specified explicitly
- **Production telemetry contract clarified**: separates required motion telemetry from optional diagnostics
- **Regression checklist added**: defines the current acceptance bench for the frozen path

**Changelog v2.2 (D033):**
- **Waypoint infrastructure removed**: CAN IDs 0x005, 0x01B, 0x01C, 0x380-0x39F removed from firmware
- **Waypoint buffer deleted**: No more 2000-waypoint buffer per DOF
- **Movement control**: Now exclusively via SET_IMPEDANCE (0x01D/0x01E)
- **Sections 4.2.5, 4.2.6, 4.2.7, 5, 6 marked as REMOVED** (retained as historical reference)

**Changelog v2.1:**
- **Re-anchor policy aligned to implementation**:
  - Firmware default `wp_reanchor_interval = 50`
  - `0 = disabled`
  - Values above `WAYPOINT_BUFFER_DEPTH` are clamped (currently 2000)
  - Host UI/API aligned to range `0..2000`

**Changelog v2.1:**
- **CAN ID 0x01D**: Added SET_IMPEDANCE (variable-frame, 1-4 frames per command)
- **CAN ID 0x01E**: Added IMPEDANCE_CTRL (disable/enable/watchdog)
- **CAN ID Table**: Updated reserved range from 0x01D-0x13F to 0x01F-0x13F (superseded by v2.4: `0x01F` is now FAULT_SNAPSHOT_CTRL)

**Changelog v2.0:**
- **Consolidated**: Merged `CAN_CONTROL_PROTOCOL.md` and `jetson-streaming-can.md` into this document
- **Updated architecture**: Jetson direct CAN path with no Pico dispatcher in the production path
- **Batch anchor timing**: Documented firmware-side anchor + consume-side re-anchor
- **Buffer depth**: Updated from 2 to 2000 (20s @ 100 Hz)
- **CAN ID 0x01B**: Added Re-anchor Interval command
- **Removed**: Obsolete timeline/milestones (dates were stale)

**Changelog v1.6:**
- CAN ID Table Updated: Documented all operational CAN IDs 0x005-0x01A (Phases 1-3 migration)

**Changelog v1.5:**
- Batch Timing Compensation: Added documentation for waypoint batch timing

**Changelog v1.4:**
- Encoder Pico eliminated: Direct MT6835 reading via SPI0 on joint controller

**Changelog v1.3:**
- Removed Single-DOF Waypoint (0x300-0x31F): Deprecated in favor of Multi-DOF format

---

## 1. Executive Summary

This document describes the complete CAN-based communication architecture for the Alia humanoid robot, designed to support up to 20 joint controllers with 80+ motors in a scalable, reliable, and cost-effective manner.

### Key Design Decisions:
- **Multi-Bus Architecture**: Dedicated CAN bus per joint controller (point-to-point, no bus sharing)
- **Dual CAN per Joint**: Host CAN (commands/telemetry) + Motor CAN (torque/status) — electrically isolated
- **Protocol**: CAN 2.0; current default is `Host CAN = 500 kbps`, `Motor CAN = 1 Mbps` (upgradeable to CAN FD)
- **Control Frequency**: 500 Hz (motor PID), `SET_IMPEDANCE` sender cadence frozen at 50 Hz for the current validated Jetson bench path
- **Latency**: < 1 ms single frame transit
- **Hardware Platform**: Nvidia Jetson direct CAN + 4x CAN Expansion Boards (8ch each)
- **Timing**: Rolling segment generation on firmware — immune to sender-side jitter

### v1 Test Baseline (frozen config):

| Parameter | Value |
|---|---|
| CAN Expansion Boards | 4x (8ch each, MCP2515 + SN65HVD230 target / TJA1050 prototype) |
| Jetson SPI buses | 4 (SPI0-SPI3) |
| Joint controllers | 20x RP2350 Pico 2 |
| CAN channels used | 20 (dedicated, one per joint) |
| Motors | 80 (4x LKM per joint) |
| Host CAN default bitrate | 500 kbps |
| Motor CAN bitrate | 1 Mbps |
| Communication cost | ~900 EUR (see §11.1) |

Operational note (2026-04-10):
- `Host CAN` is now frozen to `500 kbps` as the default runtime/update baseline.
- `1 Mbps` remains available only as a diagnostic override until the final harness is validated end-to-end.
- On `2026-04-10`, a board-local cross-chip stress test (`J4↔J5` bridged with the same CAT5 link)
  passed both at boot and at runtime inside the full firmware loop using `CMD:CAN_DIAG_CROSS`:
  `512/512` frames each direction, `0` send failures, `0` timeouts, `0` mismatches.
- Therefore the current `500 kbps` default is a robustness choice for the external host path
  (`Mac/adapter/backend/transients`), not a proven limit of the RP2350 controller firmware.

### Comparison with Commercial Robots:
- **Similar to**: Figure 01 (CAN 2.0 multi-bus), Tesla Optimus (multi-bus approach)
- **More economical than**: Boston Dynamics Atlas (EtherCAT), Agility Digit (EtherCAT)
- **More reliable than**: Single-bus architectures (Unitree H1 RS485)

---

## 2. System Overview

### 2.1 Architecture Diagram

```
┌──────────────────────────────────────────────────────────────────┐
│  NVIDIA JETSON (Central Computer)                                │
│  ├─ SPI0 → CAN Expansion Board #1 (8ch: Left Leg 6 + spare 2)  │
│  ├─ SPI1 → CAN Expansion Board #2 (8ch: Right Leg 6 + Torso 2) │
│  ├─ SPI2 → CAN Expansion Board #3 (8ch: Left Arm)               │
│  └─ SPI3 → CAN Expansion Board #4 (8ch: Right Arm)              │
└────┬─────────┬─────────┬─────────┬─────────┬─────────┬──────────┘
     │         │         │         │         │         │
  CAN ch0  CAN ch1  CAN ch2  CAN ch3  CAN ch4  CAN ch5  ... (v1: 20, max 26)
     │         │         │         │         │         │
┌────▼────┐┌───▼────┐┌───▼────┐┌───▼────┐┌───▼────┐┌───▼────┐
│ Pico 1  ││ Pico 2 ││ Pico 3 ││ Pico 4 ││ Pico 5 ││ Pico 6 │ ...
│ Joint 1 ││ Joint 2││ Joint 3││ Joint 4││ Joint 5││ Joint 6│
└────┬────┘└───┬────┘└───┬────┘└───┬────┘└───┬────┘└───┬────┘
     │         │         │         │         │         │
  4x Motors 4x Motors 4x Motors 4x Motors 4x Motors 4x Motors
```

Each joint controller has a **dedicated CAN channel** on the expansion board (point-to-point, no bus sharing between joints). Communication is bidirectional: Host → Controller for commands (SET_IMPEDANCE, TimeSync), Controller → Host for telemetry (JOINT_STATE, encoder stream). The Jetson sends CAN frames directly to joint controllers without intermediate hardware (see Section 7 for rationale).

### 2.2 Key Components

| Component | Quantity | Function | Cost (EUR) |
|---|---|---|---|
| Nvidia Jetson (Orin Nano/NX) | 1 | Central computer, trajectory planning | 400-600 |
| CAN Expansion Boards (8ch) | 4 | SPI-to-CAN (32 channels; v1: 20 used, max 26) | 496 |
| RP2350 (Pico 2) + motor CAN | 20 | Joint controller, motor PID control | 270 |
| Cabling (CAN + SPI + power) | - | Point-to-point wiring | 132 |
| LKM Servo Motors | 80 | Actuators (4 per joint) | External |
| **TOTAL COMMUNICATION** | | | **~900** |

**Notes**:
- Using **RP2350 (Pico 2)** instead of RP2040 for improved performance and future-proofing.
- **Transceiver choice**: Prototype boards use TJA1050 (5V, requires level shifting). Target production boards use SN65HVD230 (3.3V native, directly compatible with Jetson logic). See Section 3.1 for details.

### 2.3 CAN Bus Allocation (Current Plan)

**v1 Baseline: 20 CAN channels** (one per joint). Expansion capacity: up to 26 channels (6 spare across 4 boards).

#### Lower Body (12 channels):
```
Option A: Separate Legs (6 + 6)
├─ Left Leg (6 channels)
│  ├─ Ankle Plantarflexion/Dorsiflexion
│  ├─ Ankle Inversion/Eversion
│  ├─ Knee Flexion/Extension
│  ├─ Hip Flexion/Extension
│  ├─ Hip Abduction/Adduction
│  └─ Hip Internal/External Rotation
│
└─ Right Leg (6 channels)
   ├─ Ankle Plantarflexion/Dorsiflexion
   ├─ Ankle Inversion/Eversion
   ├─ Knee Flexion/Extension
   ├─ Hip Flexion/Extension
   ├─ Hip Abduction/Adduction
   └─ Hip Internal/External Rotation

Option B: Combined Legs (12 channels on 2 boards)
└─ Both Legs (12 channels)
   ├─ CAN Expansion Board #1 (8 channels): Left leg + 2 right leg
   └─ CAN Expansion Board #2 (4 channels): Remaining right leg

Recommendation: Option A (separate legs)
```

#### Upper Body (12-16 channels, indicative):
```
├─ Left Arm (6-8 channels)
├─ Right Arm (6-8 channels)
└─ Torso/Head (1-2 channels)
```

#### Hardware Configuration:

| Body Region | Channels | CAN Expansion Board | Notes |
|---|---|---|---|
| **Left Leg** | 6 | Board #1 (channels 0-5) | Isolated for reliability |
| **Right Leg** | 6 | Board #2 (channels 0-5) | Isolated for reliability |
| **Left Arm** | 6-8 | Board #3 (channels 0-7) | Full 8-channel board |
| **Right Arm** | 6-8 | Board #4 (channels 0-7) | Full 8-channel board |
| **Torso/Head** | 1-2 | Board #2 (channels 6-7) | Shared with right leg |
| **TOTAL** | **20-26** | **4 boards** | Scalable design |

---

## 3. Hardware Architecture

### 3.1 CAN Expansion Board Design

**Purpose**: Interface Jetson SPI to multiple CAN buses

**Specifications per board (8 channels):**
- **Input**: Jetson SPI (MOSI, MISO, SCK, CS)
- **Output**: 8x independent CAN buses (CANH, CANL, GND)
- **Components per channel**:
  - 1x MCP2515 CAN Controller (SPI interface)
  - 1x TJA1050 CAN Transceiver (physical layer)
  - 1x 120 ohm termination resistor (switchable)
- **SPI Multiplexing**: 74HC4051 or similar (8:1 mux)
- **Power**: 5V input, 3.3V regulation for MCP2515
- **Mounting**: DIN rail compatible
- **Connectors**: Screw terminals for CAN bus

**PCB Layout:**
```
┌─────────────────────────────────────────────────────────────┐
│  CAN Expansion Board (8 Channels)                          │
│                                                             │
│  [Jetson SPI Connector]                                    │
│         │                                                   │
│    ┌────▼─────┐                                           │
│    │ SPI Mux  │ (74HC4051)                                │
│    │ 1→8      │                                           │
│    └─┬──┬──┬──┘                                           │
│      │  │  │  ...                                         │
│   ┌──▼──┐ ┌──▼──┐ ┌──▼──┐                               │
│   │MCP  │ │MCP  │ │MCP  │ ... (8x)                      │
│   │2515 │ │2515 │ │2515 │                               │
│   └──┬──┘ └──┬──┘ └──┬──┘                               │
│   ┌──▼──┐ ┌──▼──┐ ┌──▼──┐                               │
│   │TJA  │ │TJA  │ │TJA  │ ... (8x)                      │
│   │1050 │ │1050 │ │1050 │                               │
│   └──┬──┘ └──┬──┘ └──┬──┘                               │
│      │      │      │                                     │
│   [CAN0] [CAN1] [CAN2] ... [CAN7] (Screw Terminals)     │
│    H L G  H L G  H L G                                   │
└─────────────────────────────────────────────────────────────┘
```

**Bill of Materials (per board):**

| Component | Quantity | Unit Cost | Total |
|---|---|---|---|
| MCP2515 | 8 | 6 EUR | 48 EUR |
| CAN Transceiver (*) | 8 | 2.50 EUR | 20 EUR |
| 74HC4051 | 1 | 1 EUR | 1 EUR |
| PCB (4-layer) | 1 | 30 EUR | 30 EUR |
| Connectors | 10 | 2 EUR | 20 EUR |
| Passives | - | 5 EUR | 5 EUR |
| **TOTAL** | | | **124 EUR** |

(*) Prototype: TJA1050 (5V, requires level shifting). Target: SN65HVD230 (3.3V native).

**Production:**
- **PCB Manufacturer**: Reputable quick-turn PCB vendor
- **Assembly**: PCBA service or DIY
- **Lead Time**: 2-3 weeks
- **Quantity**: 4 boards (20-26 channels used)

#### Component Selection for Custom PCB

**Recommended BOM:**
1. **CAN Controller**: `Microchip MCP2515-I/SO` (SOIC-18) — industry standard, robust Linux driver
2. **CAN Transceiver**: `Texas Instruments SN65HVD230` (SOIC-8) — runs on 3.3V natively, eliminates level shifting
3. **SPI Multiplexer**: `Texas Instruments SN74HC4051D` (SOIC-16)
4. **Crystal**: `8.000 MHz` (SMD 5032 or HC-49) — one per MCP2515

#### Power Strategy
- **Logic Power (3.3V)**: Can be drawn from Jetson header (Pins 1, 17) if total current < 500mA
  - 20x MCP2515 + 20x Transceivers ~ 300mA. Safe.
- **Bus Isolation**: Ideally, use an isolated DC/DC converter for electrically noisy environments

### 3.2 Joint Controller (RP2350 Pico 2)

**Current Implementation:**
- **Microcontroller**: RP2350 (Dual-core ARM Cortex-M33 @ 150 MHz)
- **CAN Interface**: 2x MCP2515 via SPI1 (Motor CAN + Host CAN)
- **Motor Interface**: 4x LKM Servo (CAN bus)
- **Encoder Interface**: Direct MT6835 reading via SPI0 (up to 3 encoders)
- **Firmware**: Arduino framework (PlatformIO)

**Multicore Architecture:**
- **Core0**: SPI0 — encoder reading (MT6835, ~500 Hz), serial (diagnostics only), flash operations
- **Core1**: SPI1 — CAN polling + motor control + movement execution (~500 Hz)
- **SPI Isolation**: Core0 owns SPI0 (encoders), Core1 owns SPI1 (CAN). No cross-core SPI access.

**Key Firmware Features:**
- **Impedance control**: SET_IMPEDANCE rolling target with local linear segment generation
- **Time synchronization**: NTP-like protocol via CAN
- **Flash storage**: Encoder offsets, PID parameters, linear equations (with multicore sync)

**Memory Usage (RP2350):**
- **RAM**: ~20 KB / 520 KB (3.8%)
- **Flash**: ~178 KB / 4096 KB (4.3%)

### 3.3 CAN Bus Physical Layer

**Cable Specifications:**
- **Type**: Twisted pair (120 ohm characteristic impedance)
- **Gauge**: 24 AWG (0.5 mm2)
- **Max Length**: 40 m @ 1 Mbps (per bus)
- **Shielding**: Optional (recommended in noisy environments)

**Termination:**
- **120 ohm resistor** at both ends of each bus
- **Switchable** on CAN Expansion Board
- **Always enabled** on Pico side

**Connectors:**
- **Expansion Board**: Screw terminals (CANH, CANL, GND)
- **Pico**: JST-XH 3-pin or similar
- **Color Code**: CANH=Yellow, CANL=Green, GND=Black

---

## 4. Communication Protocol

### 4.1 CAN Message Format

**Frame Structure (CAN 2.0A, 11-bit ID):**
```
┌──────────┬────────┬────────────────────────────────┬─────┐
│ CAN ID   │ Length │ Data (0-8 bytes)              │ CRC │
│ (11-bit) │ (4-bit)│                                │     │
└──────────┴────────┴────────────────────────────────┴─────┘
```

**CAN Priority Rule**: Lower CAN ID = Higher Priority (CAN arbitration)

| ID Range | Purpose | Priority | Frequency | Direction |
|---|---|---|---|---|
| 0x000 | Emergency Stop | **Level 0** (Highest) | On-demand | Host → All |
| 0x002-0x004 | System Control (TimeSync, Encoder, PID Diag) | **Level 1** (System) | On-demand | Host → Ctrl |
| 0x01D-0x01F | Impedance/Fault Control (SET_IMPEDANCE, IMPEDANCE_CTRL, FAULT_SNAPSHOT_CTRL) | **Level 1** (System) | 200 Hz / sporadic | Host → Ctrl |
| 0x140-0x280 | Motor Torque Commands | **Level 2** (CRITICAL) | 500 Hz | Ctrl → Motors |
| ~~0x380-0x39F~~ | ~~Waypoint Commands~~ | | | **REMOVED (D033)** |
| 0x400-0x4FF | Status/Feedback | **Level 3** (Lowest) | 10-50 Hz | Ctrl → Host |

**Key Design**: Motor torque commands (0x140-0x280) have **higher priority** than impedance and status commands to ensure the inner PID loop @ 500 Hz is never starved.

### 4.2 Message Types

#### 4.2.1 Emergency Stop (ID: 0x000)

**Purpose**: Immediately stop all motors (highest priority)

```cpp
struct CanCmd_EmergencyStop {
    uint8_t  reason_code;     // Stop reason (user, limit, error, etc.)
    uint8_t  reserved[7];
} __attribute__((packed));   // 8 bytes
```

**Latency**: < 500 us (highest CAN priority)
**Action**: All controllers stop motors immediately

#### 4.2.2 Time Sync (ID: 0x002)

**Purpose**: Synchronize all controllers with host absolute time

```cpp
struct CanCmd_TimeSync {
    uint32_t t_host_ms;       // Host epoch time (milliseconds, little-endian)
    uint32_t reserved;
} __attribute__((packed));   // 8 bytes
```

**Frequency**: Sent periodically at ~10 Hz for clock maintenance (used by impedance segment evaluation)

**Controller Processing:**
```cpp
void handleTimeSyncFrame(const uint8_t *data, uint8_t len) {
    uint32_t t_host_ms = 0;
    memcpy(&t_host_ms, data, sizeof(uint32_t));
    const uint32_t t_local = millis();
    clock_offset_ms = static_cast<int32_t>(t_host_ms) - static_cast<int32_t>(t_local);
    clock_synced = true;
}
```

#### 4.2.3 Encoder Stream Control (ID: 0x003)

```
Byte 0:   uint8_t  action (0x01 = start, 0x00 = stop)
Byte 1-7: Reserved (0x00)
```

**Encoder Stream Data (ID: 0x410):**
```
Byte 0:     uint8_t   joint_id
Byte 1-2:   int16_t   angle_dof0 (0.01 deg resolution)
Byte 3-4:   int16_t   angle_dof1 (0x7FFF = unused)
Byte 5-6:   int16_t   angle_dof2 (0x7FFF = unused)
Byte 7:     uint8_t   timestamp_offset (ms since last packet, wraps at 255)
```
**Stream Rate**: 50 Hz (20ms interval)

#### 4.2.4 PID Diagnostics Control (ID: 0x004)

```
Byte 0:   uint8_t  action (0x01 = start streaming, 0x00 = stop)
Byte 1:   uint8_t  terms_enabled (0x01 = enable P/I/D breakdown, 0x00 = disable)
Byte 2-7: Reserved
```

**PID Diag: Target + Error (0x420 + joint_id):**
```
Byte 0-1:  int16_t  target_angle (0.01 deg)
Byte 2-3:  int16_t  actual_angle (0.01 deg)
Byte 4-5:  int16_t  error (0.01 deg)
Byte 6-7:  Reserved
```

**PID Diag: Torque A + B (0x430 + joint_id):**
```
Byte 0-1:  int16_t  torque_agonist
Byte 2-3:  int16_t  torque_antagonist
Byte 4-5:  int16_t  torque_agonist_filtered
Byte 6-7:  int16_t  torque_antagonist_filtered
```

**PID Diag: Inner PID Terms (0x470 + joint_id) — optional, DOF 0 only:**
```
Byte 0-1:  int16_t  p_term
Byte 2-3:  int16_t  i_term
Byte 4-5:  int16_t  d_term
Byte 6-7:  int16_t  ff_term
```

**PID Diag: Outer PID Terms (0x480 + joint_id) — optional, DOF 0 only:**
```
Byte 0-1:  int16_t  p_term
Byte 2-3:  int16_t  i_term
Byte 4-5:  int16_t  d_term
Byte 6-7:  int16_t  output_x100
```

#### 4.2.5 Interpolation Mode (ID: 0x005)

**⚠️ REMOVED (D033, 2026-03-15)** — Waypoint infrastructure removed. Movement now uses SET_IMPEDANCE (0x01D/0x01E) exclusively.

```
Byte 0:   uint8_t  mode (0 = LINEAR, 1 = COSINE)
Byte 1-7: Reserved
```

Sent once before the first waypoint batch. Determines interpolation curve between consecutive waypoints.

#### 4.2.6 Re-anchor Interval (ID: 0x01B)

**⚠️ REMOVED (D033, 2026-03-15)** — Waypoint infrastructure removed. Movement now uses SET_IMPEDANCE (0x01D/0x01E) exclusively.

```
Byte 0-1: uint16_t interval
          - 0 = disabled
          - 1..2000 = re-anchor every N consumed waypoints
          - >2000 values are clamped to 2000 in firmware/host
Byte 2-7: Reserved
```

Sent before each batch. Controls consume-side drift compensation frequency. See Section 5.2.

**Current implementation policy**:
- Firmware default at boot: `50` waypoints
- UI default: `50`
- Host/API and firmware clamp maximum to `WAYPOINT_BUFFER_DEPTH` (currently `2000`)
- **Coupling note**: Host constants must stay aligned with firmware `WAYPOINT_BUFFER_DEPTH`

#### 4.2.7 Multi-DOF Waypoint (ID: 0x380-0x39F)

**⚠️ REMOVED (D033, 2026-03-15)** — Waypoint infrastructure removed. Movement now uses SET_IMPEDANCE (0x01D/0x01E) exclusively.

**Purpose**: Stream target positions for all DOFs of a joint in a single frame

```
Byte 0-1:  int16_t  dof0_angle (0.01 deg resolution, 0x7FFF = unused)
Byte 2-3:  int16_t  dof1_angle (0.01 deg resolution, 0x7FFF = unused)
Byte 4-5:  int16_t  dof2_angle (0.01 deg resolution, 0x7FFF = unused)
Byte 6-7:  uint16_t t_offset_ms (offset from batch anchor, 0-65535 ms)
```

**CAN ID**: `0x380 + joint_id` (0x380 = Ankle Right, 0x381 = Ankle Left, etc.)

**Key Features:**
- All DOFs in a single CAN frame (8 bytes)
- 66% less CAN traffic compared to per-DOF frames
- Explicit synchronization between DOFs
- `t_offset_ms` is relative to batch anchor, NOT to current time (see Section 5.1)

**Unused DOF Handling:**
- For joints with fewer than 3 DOFs, set unused angles to `0x7FFF` (sentinel)
- Controller skips DOFs with sentinel value
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

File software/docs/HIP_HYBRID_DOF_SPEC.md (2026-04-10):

# HIP Hybrid DOF Specification

**Status:** Draft Design  
**Date:** 2026-03-29  
**Scope:** Align firmware/host architecture with the real hip hardware topology before single-joint HIP validation

---

## 1. Problem Statement

The current software model treats the hip as:
- `3 DOF`
- `6 motors`
- `2 motors per DOF`
- all DOFs modeled as **antagonistic tendon-driven pairs**

This is not the real hardware.

### Real hardware model
The actual hip is conceptually:
- **DOF 0**: tendon-driven antagonistic pair
- **DOF 1**: tendon-driven antagonistic pair
- **DOF 2 (roll)**: **single direct-drive motor**, mounted directly on the thigh, rotating the leg around its own axis
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

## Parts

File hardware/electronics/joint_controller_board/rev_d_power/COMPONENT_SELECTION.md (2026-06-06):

# rev_d_power Component Selection

## Scope

This note freezes the first-pass component selection for the new `rev_d_power` board.

It is intentionally limited to the main protection and regulation devices needed to move from architecture to real schematic capture.

## Selected Topology

### Motor branch

- raw `24V` input
- local switched branch controlled by a dedicated hot-swap / eFuse controller
- external back-to-back N-MOSFET pass stage
- no raw daisy-chain output on this board; branch fan-out is handled by the upstream PDU

### Logic rail

- raw `24V` to regulated `5V`
- local `5V` to `3V3_AUX` LDO for status / sensing only

## Primary Selected Parts

### 1. High-side hot-swap / eFuse controller

- **Selected device:** `TPS2492`
- **Manufacturer:** Texas Instruments
- **Function:** positive high-voltage hot-swap controller with power limiting

Why this device:
- supports `9V` to `80V`, which is comfortably above the `24V` bus
- drives an **external N-FET** stage, so the switched path can be sized for the HIP current envelope
- provides **fixed 50 mV current-limit threshold**, **programmable FET power limit**, and **programmable fault timer**
- provides both **power-good** and **fault** outputs, which align well with the RJ45 interface contract
- the `TPS2492` variant is **latch-off after fault**, which is the safer default for a joint power stage than autonomous retry

Implementation note:
- use `TPS2493` only if auto-retry is explicitly desired later
- final `PWRGD_N` / `FAULT_N` polarity conditioning will be handled during schematic capture if the native output polarity does not match the RJ45 naming convention
- the current-limit threshold is not independently programmable; continuous vs transient behavior must be split between `R_SENSE`, `PROG`, `TIMER`, and firmware supervision through `IMON`
- first-pass recommendation was `R_SENSE = 1.25 mOhm`, **4-terminal / Kelvin sensed**, `>= 2W`, for an electronic current limit of about `40 A`
- the PCBWay first assembly lot uses the approved substitution `Vishay Dale WSR31L500FEA`: `1.5 mOhm`, `1%`, `3W`, same `WSR2/WSR3` 4527 J-lead compatible Kelvin footprint. With the `TPS2492` fixed 50 mV sense threshold, this sets `Ilim ≈ 33.3 A`
- current rev_d_power freeze leaves `IMON` unexposed because the RJ45 pin budget is full; future continuous-current firmware monitoring requires either sacrificing one voltage-monitor pin or adding a bench-only test point
- size `PROG` from the MOSFET SOA during startup, not only from steady-state load current

### 2. External switched-path MOSFETs

- **Selected device:** `BSC016N06NS`
- **Manufacturer:** Infineon
- **Function:** external pass MOSFETs for the switched `24V` motor branch

Use as:
- **2 devices in back-to-back configuration**
- orientation chosen to block both directions when OFF and allow bidirectional current flow when ON

Why this device:
- `60V` `VDS` rating gives a sensible margin for a `24V` bus with board-level surge suppression
- `1.6 mOhm max RDS(on)` at `10V`
- compact `SuperSO8 5x6` package
- strong current and thermal capability for this board class

Design note:
- a single back-to-back pair is the first choice for compactness
- if later inrush / SOA validation shows insufficient margin, the next step is **parallel back-to-back pairs**, not a lower-grade controller
- at the frozen HIP envelope (`22 A` continuous, `40 A`-class transient), one pair remains acceptable with disciplined thermal layout
- reserve layout option space for a second parallel pair if enclosure temperature or copper area proves insufficient

### 3. Main `24V -> 5V` buck regulator

- **Selected device:** `LMR36520`
- **Manufacturer:** Texas Instruments
- **Function:** main logic supply regulator for `+5V_FROM_POWER`

Why this device:
- `4.2V` to `65V` input range with transient tolerance up to `70V`
- `2A` output capability, which gives comfortable margin above the current frozen requirement of `5V @ 1A continuous`
- integrated synchronous power stage
- compact solution with internal compensation and power-good output
- materially more robust than choosing a `36V`-class regulator on a motor bus

Design note:
- the board requirement is currently only `1A continuous`
- the `2A` class is selected deliberately to reduce thermal stress and leave room for future controller-side growth
- first-pass passive targets are `L = 12 uH ... 15 uH`, `CIN = 4.7 uF / >=50V`, `COUT = 47 uF`, `RFBT = 100k`, `RFBB = 24.9k`, `CBOOT = 100 nF`
- keep the `VIN` / `PGND` / switch loop physically tight; this is one of the main EMI-sensitive loops on the board

### 4. Auxiliary `5V -> 3V3` LDO

- **Selected device:** `TLV75533P`
- **Manufacturer:** Texas Instruments
- **Function:** `3V3_AUX` rail for sensing, pull-ups, and status logic

Why this device:
- `500mA` output capability is far above the expected auxiliary load
- input range up to `5.5V`, perfect for a regulated `5V` upstream rail
- low quiescent current
- small package and simple implementation
- integrated soft-start, UVLO, current limit, and thermal shutdown

Design note:
- this rail is **not** intended to power the logic board
- it exists only so that the power board can generate Pico-safe status levels locally

### 5. Input surge suppressor

- **Selected device:** `SMCJ33A`
- **Type:** unidirectional TVS

Why this device:
- better surge capability than the currently drafted `SMBJ33CA`
- unidirectional TVS is the correct choice for a DC rail
- `33V` standoff is appropriate for a `24V` nominal bus

Design note:
- keep the TVS physically close to the raw input connector and return path
- `SMCJ33A` remains the default first-prototype choice; `SMCJ30A` is a possible follow-up only if extra clamping margin is needed after bench transient testing

## Branch Fuse (moved off-board — Option C1)

The per-branch protection fuse has been **removed from the rev_d_power board**
and is now expected on the upstream PDU / battery distribution board.

Rationale:
- the on-board `TPS2492` provides primary fast protection via its fixed
  50 mV current-limit (`Ilim ≈ 33.3 A` on the PCBWay first lot with
  `R_SENSE = 1.5 mOhm`; original 1.25 mΩ target would give about 40 A)
- an on-board slow-blow fuse would protect the board but not the cable feeding
  it — a cable short upstream of the board cannot be interrupted by an on-board
  device
- a single central PDU is the natural location for branch fuses in a 20+ joint
  humanoid: single maintenance point, uniform interchangeable fuse type, per-branch
  status LEDs / telemetry are easier to expose there
- removing the ATO holder + fuse saves ~24 mm of vertical clearance inside
  the joint enclosure, resolving the mechanical fit-check blocker seen on the
  first rev_d_power physical prototype

Recommendation for the upstream PDU:
- **30 A ATO** slow-blow per joint branch (one `Ilim`-safe fuse per joint)
- sized below `TPS2492` `Ilim` so that on-board fast protection trips first
  under transient overcurrent; the fuse only opens on catastrophic cable-side
  faults (dead short, reverse polarity, burned FET)
- harness gauge follows the joint-class policy in `ARCHITECTURE.md`:
  `12 AWG` silicone for HIP / high-current trunk runs, `14 AWG` silicone for
  knee and ankle branches, and `16 AWG` only for short single-motor runs or
  bench testing
- PCB holder form factor can be the same Littelfuse 178.6165 series used here
  previously, or a lower-profile 177.6183 (horizontal) if PDU height is
  constrained

### Sense resistor / timer / UVLO / OVLO component values

These values depend on:
- desired electronic current limit
- acceptable startup inrush duration
- output capacitance of the connected motor branch
- trip philosophy for `FAULT_N`

Current design intent:
- electronic current limit target in the `33A` to `40A` class, depending on the populated Kelvin shunt
- PCBWay first assembly lot: `R_SENSE = 1.5 mOhm` (`WSR31L500FEA`) -> `Ilim ≈ 33.3 A`
- latch-off fault behavior by default
- use Kelvin routing for the shunt and keep the `TPS2492` sense traces away from the main current path copper

## Next Capture Tasks

1. Replace the generic `HS_SWITCH_24V_TBD` placeholder with a real `TPS2492` symbol and support passives.
2. Add the back-to-back `BSC016N06NS` MOSFET pair and route the switched path around it.
3. Refine the already-instantiated `LMR36520` draft around real passive sizing, footprint finalization, and routing constraints.
4. Refine the already-instantiated `TLV75533P` draft and its local decoupling / enable strategy.
5. Freeze the passive values for `TPS2492` `UVLO` / `OVLO` / current limit / timer after the real load-side capacitance assumptions are written down.
6. Decide whether `BUCK_PG` is exposed, ignored, or repurposed internally before moving to PCB placement.

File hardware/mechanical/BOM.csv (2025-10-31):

# MECHANICAL HARDWARE - BILL OF MATERIALS
# Alia Humanoid Robot - Complete parts catalog
# Last Updated: 2025-10-27
# Total STL Files: 19
# License: CC BY-NC-ND 4.0
Part Name | Qty/Leg | Type | Material | Location/Sourcing | Cost EUR | Description
# ========== STL FILES - LOWER LEG ==========
lower_leg_frame_upper | 1 | STL | PETG/Nylon | lower_leg/right/rev_a/stl/ | - | Upper frame (knee to mid-shank) + 4× eyelets
lower_leg_frame_lower | 1 | STL | PETG/Nylon | lower_leg/right/rev_a/stl/ | - | Lower frame (mid-shank to ankle) + 12× eyelets
lower_leg_power_board_cover | 1 | STL | PETG | lower_leg/right/rev_a/stl/ | - | Power board enclosure (24V + CAN hub)
lower_leg_encoder_board_cover | 1 | STL | PETG | lower_leg/right/rev_a/stl/ | - | Encoder board enclosure (MT6835 hub)
# ========== STL FILES - ANKLE ==========
ankle_plantar_dorsal_frame | 1 | STL | PETG/Nylon | ankle/right/rev_a/stl/ | - | Plantar-dorsal DOF frame
ankle_tendon_holder_left | 1 | STL | PETG/Nylon | ankle/right/rev_a/stl/ | - | Left tendon holder (plantar-dorsal)
ankle_tendon_holder_right | 1 | STL | PETG/Nylon | ankle/right/rev_a/stl/ | - | Right tendon holder (plantar-dorsal)
ankle_inversion_eversion_frame | 1 | STL | PETG/Nylon | ankle/right/rev_a/stl/ | - | Inversion-eversion DOF + foot base plate
ankle_tendon_holder_inversion_left | 1 | STL | PETG/Nylon | ankle/right/rev_a/stl/ | - | Left tendon holder (inversion-eversion)
ankle_tendon_holder_inversion_right | 1 | STL | PETG/Nylon | ankle/right/rev_a/stl/ | - | Right tendon holder (inversion-eversion)
# ========== STL FILES - COMMON: MOTOR MOUNTS ==========
motor_mount_mg4005 | 3 | STL | PETG/ABS | common/motor_mounts/ | - | MG4005E motor mounting bracket
motor_mount_mg5010 | 1 | STL | PETG/ABS | common/motor_mounts/ | - | MG5010 motor mounting bracket
# ========== STL FILES - COMMON: CABLE MANAGEMENT ==========
cable_clamp_10mm | 8 | STL | PLA/PETG | common/cable_management/ | - | Semi-circular clamp Ø10mm cable bundles
# ========== STL FILES - COMMON: SENSOR MOUNTS ==========
encoder_mount_mt6835_flat | 2 | STL | PETG/Nylon | common/sensor_mounts/ | - | MT6835 encoder mount flat profile
encoder_mount_mt6835_with_spacer | 0 | STL | PETG/Nylon | common/sensor_mounts/ | - | MT6835 encoder mount with spacer (hip - Phase 2)
shaft_holder_flat | 2 | STL | PETG/Nylon | common/sensor_mounts/ | - | Shaft/bushing holder flat profile
shaft_holder_with_spacer | 0 | STL | PETG/Nylon | common/sensor_mounts/ | - | Shaft holder with spacer (hip - Phase 2)
# ========== STL FILES - COMMON: PULLEYS ==========
pulley_18mm | TBD | STL | PETG/ABS/ASA | common/pulleys/ | - | Tendon transmission pulley Ø18mm
pulley_10mm | 4 | STL | PETG/ABS/ASA | common/pulleys/ | - | Tendon transmission pulley Ø10mm (ankle motors)
# ========== COMMERCIAL PARTS - FASTENERS ==========
m3_screw_12mm | 16 | Fastener | Steel | Local/McMaster | 0.05 | ISO 4762 socket head cap screw
m3_nut | 16 | Fastener | Steel | Local/McMaster | 0.02 | ISO 4032 hex nut
m2_screw_8mm | 8 | Fastener | Steel | Local/McMaster | 0.03 | Sensor mount screws
# ========== COMMERCIAL PARTS - EYELETS ==========
eyelet_4mm_silver | 16 | Eyelet | Metal silver | Amazon | 0.05 | 4mm double-sided eyelets UHMWPE routing (4× upper + 12× lower)
cable_eyelet_2mm | 4 | Eyelet | Brass | Amazon/Local | 0.02 | 2mm brass eyelet electrical cable routing (ankle)
# ========== COMMERCIAL PARTS - BUSHINGS & PINS ==========
bushing_04x06x06 | 4 | Bushing | Oilless Bronze | Amazon Kozelo | 0.30 | Ø4mm ID × Ø6mm OD × 6mm (ankle joints)
pin_04x18 | 2 | Pin | SS316L | Amazon/Local | 0.10 | Ø4×18mm cylindrical pin (ankle DOF1)
pin_04x14 | 2 | Pin | SS316L | Amazon/Local | 0.10 | Ø4×14mm cylindrical pin (ankle DOF2)
# ========== TENDONS & ACTUATORS ==========
uhmwpe_line_8strand_250lb | 1 | Raw Material | UHMWPE PE braided | Amazon HERCULES | 0.10/m | 8-strand 250lb braided line 1000m (base material for tendons)
uhmwpe_tendon_3strand | 4 | Tendon | UHMWPE flat braid | Handmade from 8-strand | TBD | 3-strand flat braid ankle actuation (2 per DOF)
motor_lkm_mg4005 | 4 | Motor | N/A | LKMotor | TBD | Ankle actuation (2 per DOF)
# ========== FOOT (Phase 2 - Q1 2026) ==========
# foot_base | 1 | STL | PA12 Nylon | foot/right/rev_a/stl/ | - | Foot base plate (SLS print)
# foot_toe_01..05 | 5 | STL | TPU 95A | foot/right/rev_a/stl/ | - | 5× toes (FDM flexible)
# ========== NOTES ==========
# Qty/Leg: Quantities are PER LEG (multiply ×2 for complete robot)
# STL Location: Relative path from hardware/mechanical/
# Cost: TBD = To Be Determined (prototyping phase)
# Material: Recommended print material or commercial specification

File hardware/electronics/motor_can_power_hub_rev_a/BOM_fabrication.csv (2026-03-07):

Item # | *Designator | *Qty | Manufacturer | *Mfg Part # | Description / Value | *Package/Footprint | Mounting Type | Your Instructions / Notes
1 | J_PWR_IN1 | 1 | AMASS | XT60PW-M | XT60 PCB male horizontal 2-pin | Connector_AMASS:AMASS_XT60PW-M_1x02_P7.20mm_Horizontal | THT | Ingresso alimentazione V++/V--
2 | J_CAN_IN1 | 1 | Phoenix Contact | 1725656 | 3-pin terminal block 2.54mm (MPT-0,5) | TerminalBlock_Phoenix:TerminalBlock_Phoenix_MPT-0,5-3-2.54_1x03_P2.54mm_Horizontal | THT | Ingresso CAN_GND/CAN_L/CAN_H
3 | J_MOTOR1-J_MOTOR5 | 5 | JST | B6B-ZR(LF)(SN) | ZH 6-pin vertical header 1.5mm | Connector_JST:JST_ZH_B6B-ZR_1x06_P1.50mm_Vertical | THT | Uscite motori (pinout da schema)

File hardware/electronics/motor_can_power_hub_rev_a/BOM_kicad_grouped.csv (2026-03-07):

Designator | Value | Footprint | Datasheet | Description | Qty | DNP
J_CAN_IN1 | Conn_01x03 | TerminalBlock_Phoenix:TerminalBlock_Phoenix_MPT-0,5-3-2.54_1x03_P2.54mm_Horizontal | ~ | Generic connector, single row, 01x03, script generated (kicad-library-utils/schlib/autogen/connector/) | 1
J_MOTOR1-J_MOTOR5 | JST | Connector_JST:JST_ZH_B6B-ZR_1x06_P1.50mm_Vertical | ~ | Generic connector, single row, 01x06, script generated | 5
J_PWR_IN1 | Conn_01x02_Pin | Connector_AMASS:AMASS_XT60PW-M_1x02_P7.20mm_Horizontal | ~ | Generic connector, single row, 01x02, script generated | 1

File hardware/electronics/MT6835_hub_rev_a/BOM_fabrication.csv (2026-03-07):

Item # | *Designator | *Qty | Manufacturer | *Mfg Part # | Description / Value | *Package/Footprint | Mounting Type | Your Instructions / Notes
1 | J0 | 1 | Amphenol | RJHSE5380 | RJ45 8P8C shielded connector | Connector_RJ:RJ45_Amphenol_RJHSE5380 | THT | IFACE verso joint_controller J2 (encoder)
2 | J1-J3 | 3 | Molex | 53398-0671 | 6-pin PicoBlade vertical header 1.25mm | Connector_Molex:Molex_PicoBlade_53398-0671_1x06-1MP_P1.25mm_Vertical | SMD | Ingressi encoder MT6835

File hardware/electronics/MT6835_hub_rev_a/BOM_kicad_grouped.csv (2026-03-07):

Designator | Value | Footprint | Datasheet | Description | Qty | DNP
J0 | 8P8C | Connector_RJ:RJ45_Amphenol_RJHSE5380 | ~ | RJ connector, 8P8C (8 positions 8 connected), RJ31/RJ32/RJ33/RJ34/RJ35/RJ41/RJ45/RJ49/RJ61, Shielded | 1
J1-J3 | Conn_01x06_Pin | Connector_Molex:Molex_PicoBlade_53398-0671_1x06-1MP_P1.25mm_Vertical | ~ |  | 3

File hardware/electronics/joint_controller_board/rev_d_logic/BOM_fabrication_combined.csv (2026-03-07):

Designator | Footprint | Quantity | Manufacturer Part Number | Manufacturer | Description | Assembly_Type | Populate | Sourcing | Notes
U_CAN1 | SOIC-18W_7.5x11.6mm_P1.27mm | 1 | MCP2515-E/SO | Microchip | Stand-alone CAN controller with SPI interface | SMD | YES | LCSC / preferred source | CAN1 controller
U_CAN2 | SOIC-18W_7.5x11.6mm_P1.27mm | 1 | MCP2515-E/SO | Microchip | Stand-alone CAN controller with SPI interface | SMD | YES | LCSC / preferred source | CAN2 controller
U_TRX1 | SOIC-8_3.9x4.9mm_P1.27mm | 1 | SN65HVD230DR | Texas Instruments | 3.3V CAN transceiver | SMD | YES | LCSC / preferred source | CAN1 transceiver
U_TRX2 | SOIC-8_3.9x4.9mm_P1.27mm | 1 | SN65HVD230DR | Texas Instruments | 3.3V CAN transceiver | SMD | YES | LCSC / preferred source | CAN2 transceiver
U_WDT1 | SOT-23-8 | 1 | MAX6369KA+T | Analog Devices / Maxim | Pin-selectable watchdog timer | SMD | YES | LCSC / preferred source | Hardware watchdog
U4 | VSSOP-8_2.4x2.1mm_P0.5mm | 1 | SN74LVC2G08DCUR | Texas Instruments | Dual AND gate 1.65V to 5.5V | SMD | YES | LCSC / preferred source | Safety gating logic
D1 | SOT-23 | 1 | PESD2CAN24XLT-Q | Nexperia | Automotive CAN ESD protection diode | SMD | YES | LCSC / preferred source | CAN1 TVS
D2 | SOT-23 | 1 | PESD2CAN24XLT-Q | Nexperia | Automotive CAN ESD protection diode | SMD | YES | LCSC / preferred source | CAN2 TVS
D_PWR1 | D_SMA | 1 | SS24 | Multiple | Schottky diode 2A 40V SMA | SMD | YES | LCSC / preferred source | 5V input OR-ing / reverse backfeed protection
Y1 | Crystal_SMD_3225-4Pin_3.2x2.5mm | 1 | 3225 8M 12PF 10PPM | SOSET / Equivalent | 8MHz SMD crystal 3225-4P | SMD | YES | LCSC / preferred source | CAN1 clock crystal
Y2 | Crystal_SMD_3225-4Pin_3.2x2.5mm | 1 | 3225 8M 12PF 10PPM | SOSET / Equivalent | 8MHz SMD crystal 3225-4P | SMD | YES | LCSC / preferred source | CAN2 clock crystal
C2 | C_0805_2012Metric | 1 | CL21B104KBCNNNC | Samsung | 100nF 50V X7R 0805 capacitor | SMD | YES | LCSC / preferred source | Decoupling
C6 | C_0805_2012Metric | 1 | CL21B104KBCNNNC | Samsung | 100nF 50V X7R 0805 capacitor | SMD | YES | LCSC / preferred source | Decoupling
C_CAN1_VDD1 | C_0805_2012Metric | 1 | CL21B104KBCNNNC | Samsung | 100nF 50V X7R 0805 capacitor | SMD | YES | LCSC / preferred source | CAN1 MCP decoupling
C_CAN1_TRX1 | C_0805_2012Metric | 1 | CL21B104KBCNNNC | Samsung | 100nF 50V X7R 0805 capacitor | SMD | YES | LCSC / preferred source | CAN1 transceiver decoupling
C_CAN2_VDD2 | C_0805_2012Metric | 1 | CL21B104KBCNNNC | Samsung | 100nF 50V X7R 0805 capacitor | SMD | YES | LCSC / preferred source | CAN2 MCP decoupling
C_CAN2_TRX2 | C_0805_2012Metric | 1 | CL21B104KBCNNNC | Samsung | 100nF 50V X7R 0805 capacitor | SMD | YES | LCSC / preferred source | CAN2 transceiver decoupling
C_CAN1_BULK1 | C_0805_2012Metric | 1 | CL21A105KBQNNNE | Samsung | 1uF 50V X5R 0805 capacitor | SMD | YES | LCSC / preferred source | CAN1 local bulk
C_CAN2_BULK2 | C_0805_2012Metric | 1 | CL21A105KBQNNNE | Samsung | 1uF 50V X5R 0805 capacitor | SMD | YES | LCSC / preferred source | CAN2 local bulk
C_CAN1_OSC1 | C_0805_2012Metric | 1 | CL21C180JBANNNC | Samsung | 18pF C0G 50V 0805 capacitor | SMD | YES | LCSC / preferred source | CAN1 crystal load
C_CAN1_OSC2 | C_0805_2012Metric | 1 | CL21C180JBANNNC | Samsung | 18pF C0G 50V 0805 capacitor | SMD | YES | LCSC / preferred source | CAN1 crystal load
C_CAN2_OSC3 | C_0805_2012Metric | 1 | CL21C180JBANNNC | Samsung | 18pF C0G 50V 0805 capacitor | SMD | YES | LCSC / preferred source | CAN2 crystal load
C_CAN2_OSC4 | C_0805_2012Metric | 1 | CL21C180JBANNNC | Samsung | 18pF C0G 50V 0805 capacitor | SMD | YES | LCSC / preferred source | CAN2 crystal load
R1 | R_0805_2012Metric | 1 | RC0805FR-0710KL | Yageo | 10k Ohm 1% 0805 resistor | SMD | YES | LCSC / preferred source | Watchdog network
R2 | R_0805_2012Metric | 1 | RC0805FR-0710KL | Yageo | 10k Ohm 1% 0805 resistor | SMD | YES | LCSC / preferred source | Watchdog network
R3 | R_0805_2012Metric | 1 | RC0805FR-0710KL | Yageo | 10k Ohm 1% 0805 resistor | SMD | YES | LCSC / preferred source | Watchdog network
R4 | R_0805_2012Metric | 1 | RC0805FR-0710KL | Yageo | 10k Ohm 1% 0805 resistor | SMD | YES | LCSC / preferred source | Watchdog network
R5 | R_0805_2012Metric | 1 | RC0805FR-0710KL | Yageo | 10k Ohm 1% 0805 resistor | SMD | YES | LCSC / preferred source | Watchdog network
R_CAN1_RST1 | R_0805_2012Metric | 1 | RC0805FR-0710KL | Yageo | 10k Ohm 1% 0805 resistor | SMD | YES | LCSC / preferred source | CAN1 reset pull-up
R_CAN2_RST2 | R_0805_2012Metric | 1 | RC0805FR-0710KL | Yageo | 10k Ohm 1% 0805 resistor | SMD | YES | LCSC / preferred source | CAN2 reset pull-up
R_CAN1_RS1 | R_0805_2012Metric | 1 | RC0805JR-070RL | Yageo | 0 Ohm 0805 jumper resistor | SMD | YES | LCSC / preferred source | CAN1 RS strap
R_CAN2_RS2 | R_0805_2012Metric | 1 | RC0805JR-070RL | Yageo | 0 Ohm 0805 jumper resistor | SMD | YES | LCSC / preferred source | CAN2 RS strap
R_SO_SPI1 | R_0805_2012Metric | 1 | RC0805FR-0722RL | Yageo | 22 Ohm 1% 0805 resistor | SMD | YES | LCSC / preferred source | SPI SO damping
R_SO_SPI2 | R_0805_2012Metric | 1 | RC0805FR-0722RL | Yageo | 22 Ohm 1% 0805 resistor | SMD | YES | LCSC / preferred source | SPI SO damping
R_TERM_CAN1 | R_0805_2012Metric | 1 | RC0805FR-07120RL | Yageo | 120 Ohm 1% 0805 resistor | SMD | YES | LCSC / preferred source | CAN1 termination
R_TERM_CAN2 | R_0805_2012Metric | 1 | RC0805FR-07120RL | Yageo | 120 Ohm 1% 0805 resistor | SMD | YES | LCSC / preferred source | CAN2 termination
SJ_TERM_CAN1 | SolderJumper-2_P1.3mm_Open_TrianglePad1.0x1.5mm | 1 | PCB_FEATURE | NA | Solder jumper footprint on PCB | PCB | YES | PCB fabrication only | Do not add as assembled component
SJ_TERM_CAN2 | SolderJumper-2_P1.3mm_Open_TrianglePad1.0x1.5mm | 1 | PCB_FEATURE | NA | Solder jumper footprint on PCB | PCB | YES | PCB fabrication only | Do not add as assembled component
J1 | RJ45_Amphenol_RJHSE5380 | 1 | RJHSE5380 | Amphenol ICC | RJ45 8P8C right-angle THT connector | THT | YES | Consigned recommended | IFACE connector
J2 | RJ45_Amphenol_RJHSE5380 | 1 | RJHSE5380 | Amphenol ICC | RJ45 8P8C right-angle THT connector | THT | YES | Consigned recommended | Encoder connector
J_CAN1_IN1 | TerminalBlock_Phoenix_MPT-0,5-3-2.54_1x03_P2.54mm_Horizontal | 1 | 1725669 | Phoenix Contact | 3-pin pluggable terminal block 2.54mm pitch | THT | YES | LCSC / preferred source | CAN1 connector
J_CAN2_IN2 | TerminalBlock_Phoenix_MPT-0,5-3-2.54_1x03_P2.54mm_Horizontal | 1 | 1725669 | Phoenix Contact | 3-pin pluggable terminal block 2.54mm pitch | THT | YES | LCSC / preferred source | CAN2 connector
U1 | RaspberryPi_Pico_Common_THT | 2 | PPTC201LFBN-RC | Sullins / Equivalent | Female socket strip 1x20 2.54mm THT | THT | YES | Consigned or equivalent | ASSEMBLE ONLY 2x female socket strips on U1 footprint; DO NOT PLACE Raspberry Pi Pico module (customer supplied | plug-in after delivery)

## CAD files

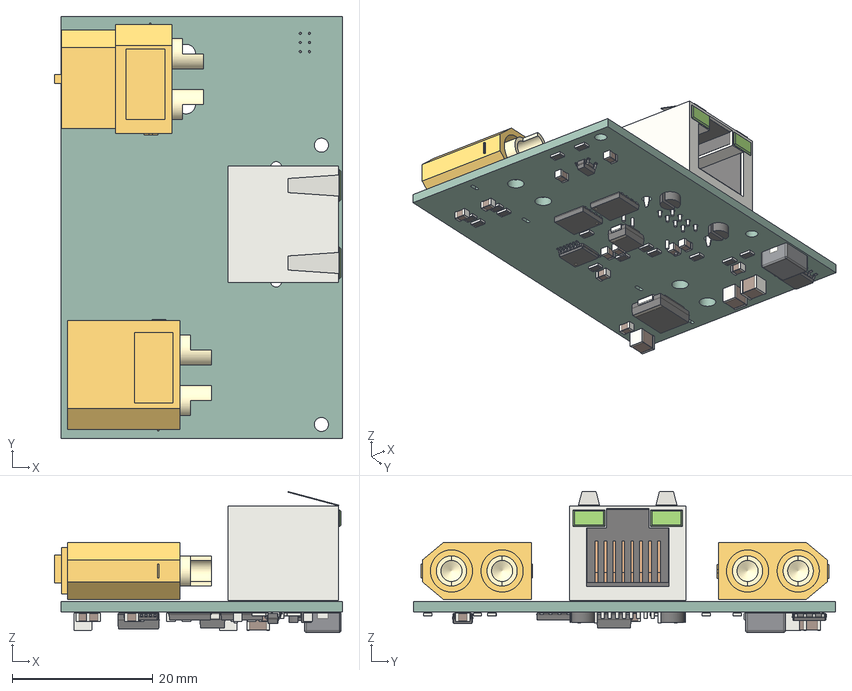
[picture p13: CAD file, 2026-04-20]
hardware/electronics/joint_controller_board/rev_d_power/joint_controller_board_rev_d_power.step
41.0 x 60.0 x 20.0 mm
AMASS_XT60PW-M_1x02_P7.20mm_Horizontal
RJ45_Amphenol_RJHSE538X
AMASS_XT60PW-F_1x02_P7.20mm_Horizontal
C_0805_2012Metric x 11
R_0805_2012Metric x 14
C_1210_3225Metric x 3
SOT-23-5
D_SMB
Texas_HTSOP-8-1EP_3.9x4.9mm_P1.27mm_EP2.85x4.9mm_Mask2.4x3.1mm_ ThermalVias
D_SMC
TDSON-8-1 x 2
L_Bourns_SRP5030T
TSSOP-14_4.4x5mm_P0.65mm
joint_controller_board_rev_d_power_PCB

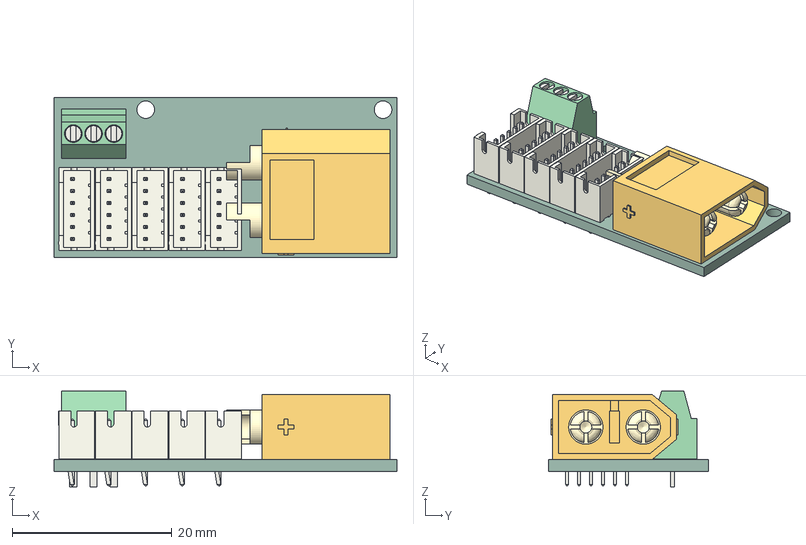
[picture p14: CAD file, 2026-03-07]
hardware/electronics/motor_can_power_hub_rev_a/motor_can_power_hub_rev_a.step
43.0 x 20.0 x 12.0 mm
JST_ZH_B6B-ZR_1x06_P1.50mm_Vertical x 5
TerminalBlock_Phoenix_MPT-0,5-3-2.54_1x03_P2.54mm_Horizontal
AMASS_XT60PW-M_1x02_P7.20mm_Horizontal
motor_can_power_hub_rev_a_PCB

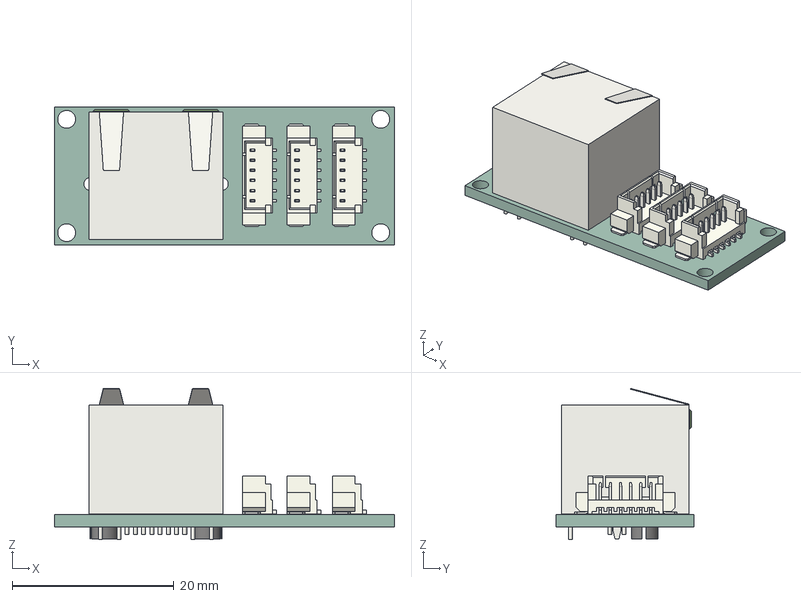
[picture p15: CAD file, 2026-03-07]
hardware/electronics/MT6835_hub_rev_a/MT6835_hub_rev_a.step
42.0 x 17.0 x 18.7 mm
Molex_PicoBlade_53398-0671_1x06-1MP_P1.25mm_Vertical x 3
RJ45_Amphenol_RJHSE538X
MT6835_hub_rev_a_PCB

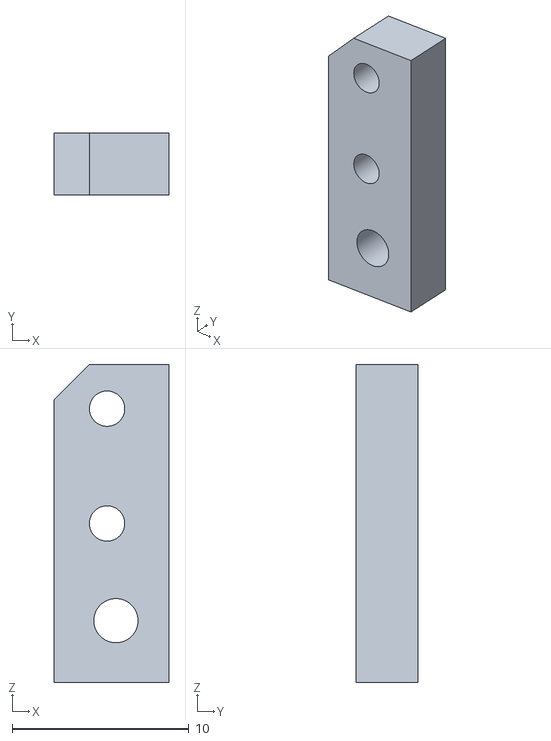
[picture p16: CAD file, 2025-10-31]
hardware/mechanical/ankle/right/rev_a/stl/ankle_tendon_holder_inversion_left.stl
6.50 x 3.50 x 18.0

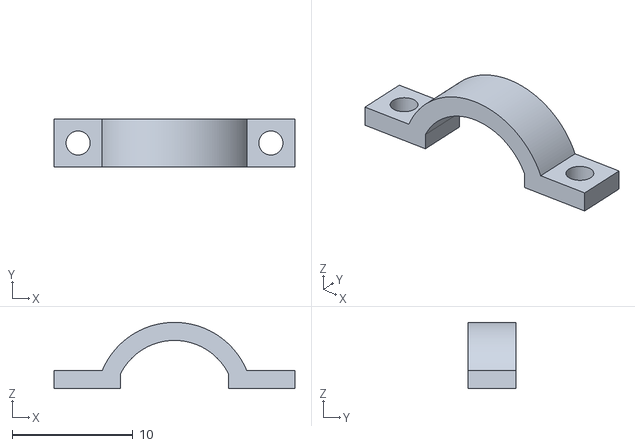
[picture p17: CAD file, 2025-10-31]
hardware/mechanical/common/cable_management/cable_clamp_10mm.stl
20.0 x 4.00 x 5.50

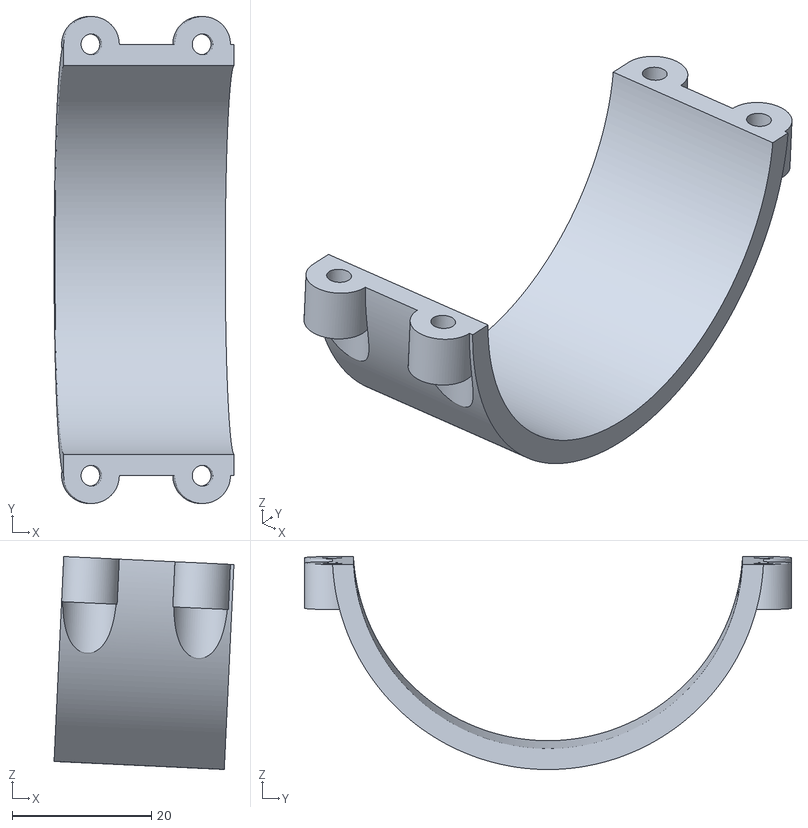
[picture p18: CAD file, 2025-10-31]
hardware/mechanical/common/motor_mounts/motor_mount_mg4005.stl
25.9 x 70.0 x 30.6

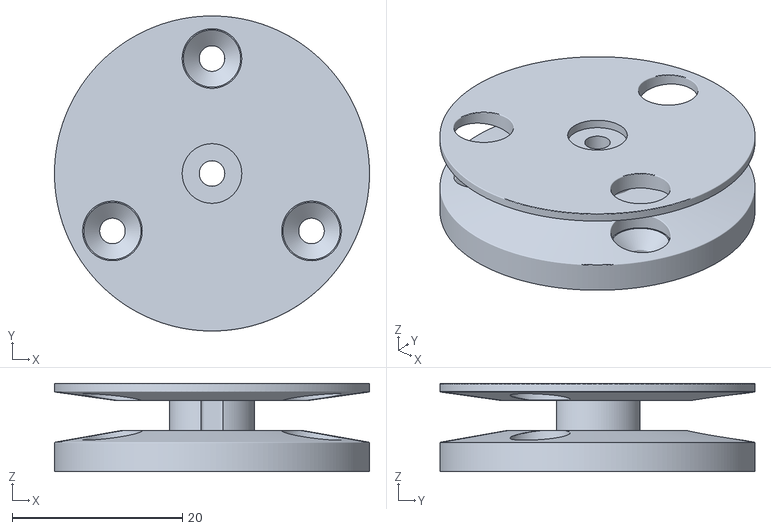
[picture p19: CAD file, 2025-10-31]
hardware/mechanical/common/pulleys/pulley_10mm.stl
37.0 x 37.0 x 10.4

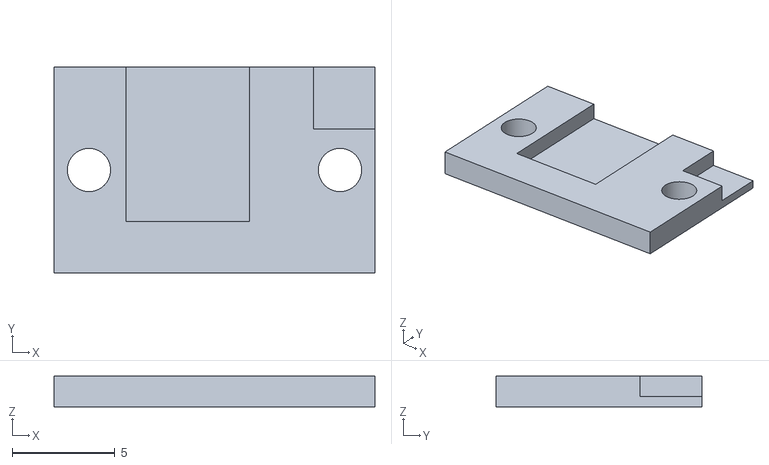
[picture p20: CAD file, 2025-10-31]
hardware/mechanical/common/sensor_mounts/encoder_mount_mt6835_flat.stl
15.6 x 10.0 x 1.50

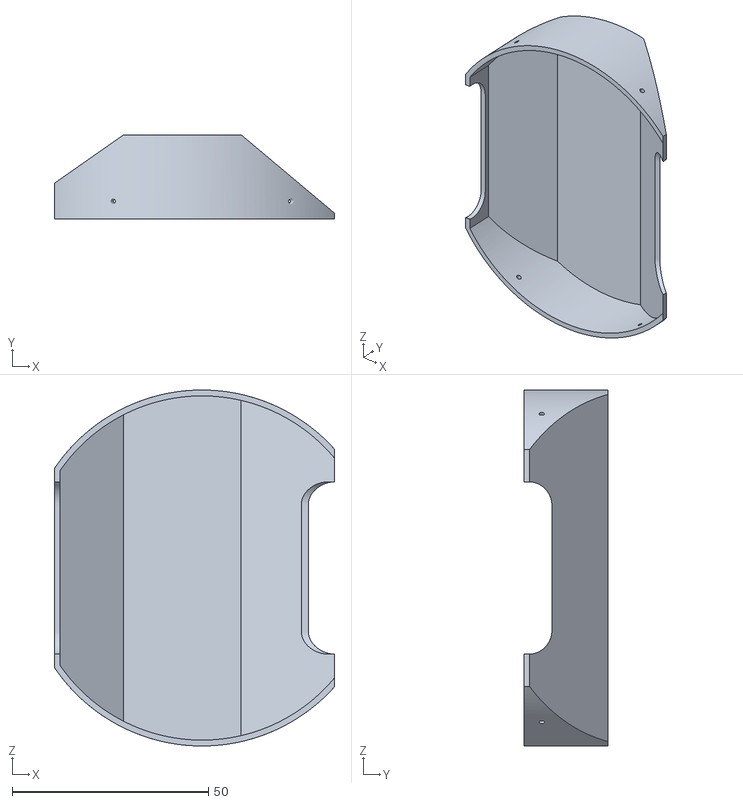
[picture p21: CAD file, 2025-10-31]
hardware/mechanical/lower_leg/right/rev_a/stl/lower_leg_power_board_cover.stl
71.5 x 21.5 x 90.8

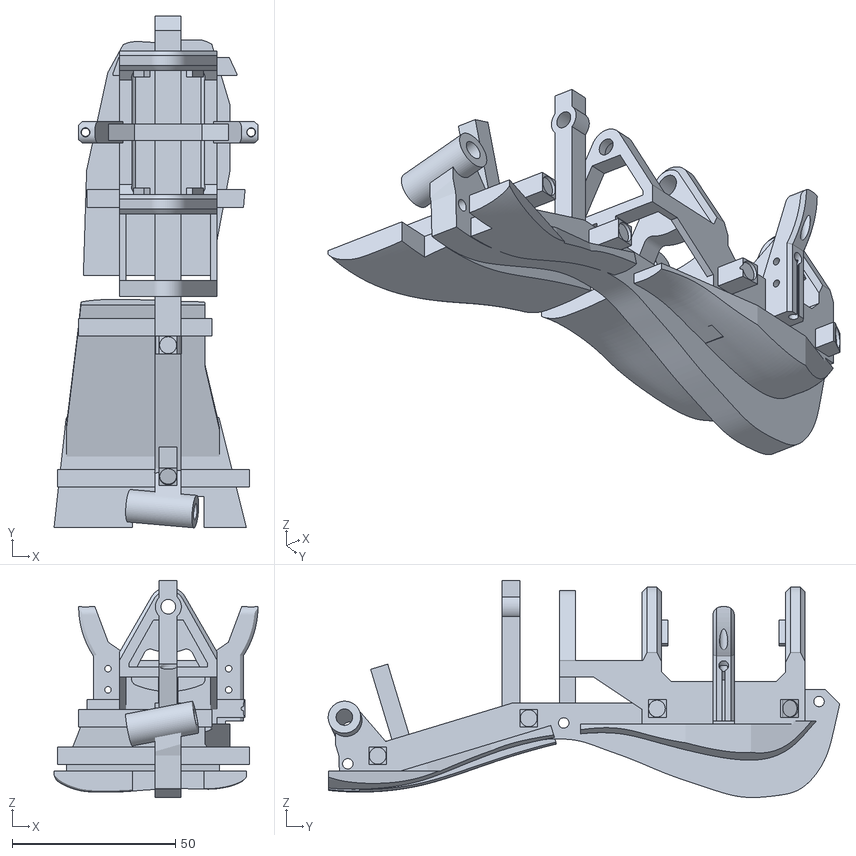
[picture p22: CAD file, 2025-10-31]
hardware/mechanical/ankle/right/rev_a/stl/ankle_inversion_eversion_frame.stl
62.6 x 156.9 x 66.6

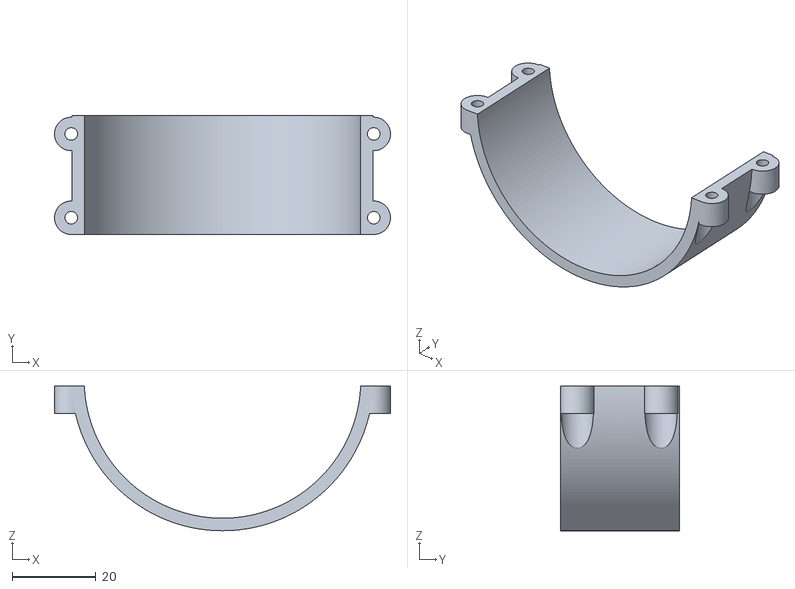
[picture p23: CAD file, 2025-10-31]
hardware/mechanical/common/motor_mounts/motor_mount_mg5010.stl
80.2 x 28.4 x 34.5

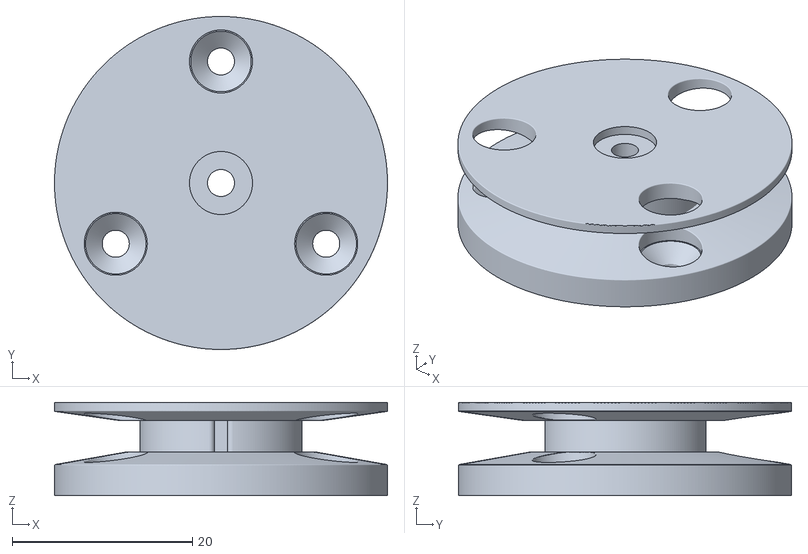
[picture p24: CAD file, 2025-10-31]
hardware/mechanical/common/pulleys/pulley_18mm.stl
37.0 x 37.0 x 10.4

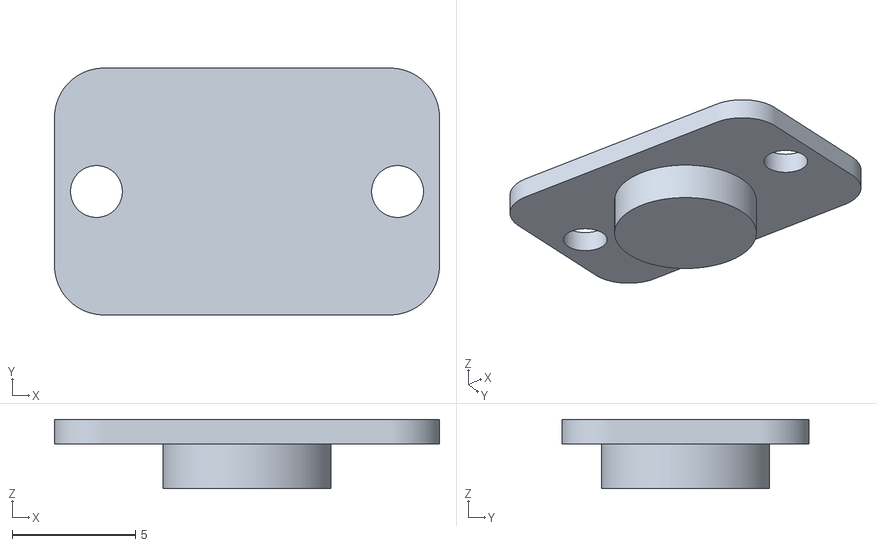
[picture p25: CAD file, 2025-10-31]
hardware/mechanical/common/sensor_mounts/shaft_holder_with_spacer.stl
15.6 x 10.0 x 2.80

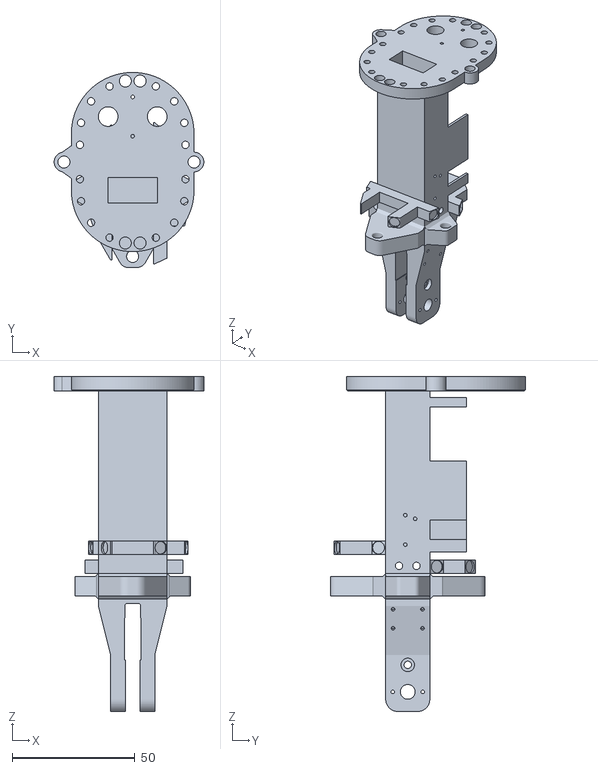
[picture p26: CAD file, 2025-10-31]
hardware/mechanical/lower_leg/right/rev_a/stl/lower_leg_frame_lower.stl
61.0 x 79.5 x 136.5

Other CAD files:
hardware/mechanical/ankle/right/rev_a/stl/ankle_tendon_holder_left.stl
hardware/mechanical/common/sensor_mounts/shaft_holder_flat.stl
hardware/mechanical/lower_leg/right/rev_a/stl/lower_leg_frame_upper.stl
hardware/mechanical/ankle/right/rev_a/stl/ankle_tendon_holder_right.stl
hardware/mechanical/ankle/right/rev_a/stl/ankle_plantar_dorsal_frame.stl
hardware/mechanical/ankle/right/rev_a/stl/ankle_tendon_holder_inversion_right.stl
hardware/mechanical/common/sensor_mounts/encoder_mount_mt6835_with_spacer.stl
hardware/mechanical/lower_leg/right/rev_a/stl/lower_leg_encoder_board_cover.stl

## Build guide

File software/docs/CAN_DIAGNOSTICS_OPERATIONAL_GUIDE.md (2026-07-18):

# CAN Diagnostics Operational Guide

## Summary

In integrated experiments, CAN is the authoritative diagnostics plane.

USB serial remains a service-only channel for single-board bring-up, recovery when the
host CAN path itself is suspect, or low-level firmware debugging at the bench. It is no
longer the primary observability path once multiple joint controllers are active.

This guide applies to the lower-body bring-up path where the Jetson talks to one joint
controller per dedicated host CAN channel.

## Diagnostic Layers

### 1. Always-On Health Plane

These frames are expected to stay available during nominal integrated experiments:

- `HEALTH_STATUS` (`0x510+joint`)
  - low-rate health summary
  - reboot reason
  - uptime and error counters
- `FAULT_STATUS` (`0x520+joint`)
  - active fault mask
  - latched fault mask
  - primary fault code
  - fault epoch
- `EVENT_NOTICE` (`0x530+joint`)
  - compact on-change event stream
  - startup milestones
  - E-stop / recovery transitions
  - fault transitions
  - snapshot-freeze notification

This plane must be enough to understand the state of every active controller without
opening serial terminals.

### 2. Deep Diagnostics On Demand

The integrated robot should not stream heavy debug telemetry from every controller at the
same time.

Use on-demand streams such as `DIAG_HOLD` and `RPROBE_RESULT` selectively:

- keep the always-on health plane enabled on all active controllers
- enable deeper diagnostics on one controller at a time unless a specific experiment
  proves a broader configuration is safe

### 3. Post-Mortem Snapshot Path

Critical fault entry freezes one controller-local snapshot in firmware.

Snapshot retrieval uses:

- `FAULT_SNAPSHOT_CTRL` (`0x01F`) from host to controller
- `FAULT_SNAPSHOT_META` (`0x540+joint`) from controller to host
- `FAULT_SNAPSHOT_DATA` (`0x550+joint`) from controller to host

The snapshot path is intended for post-mortem recovery after faults such as:

- host watchdog timeout
- invalid encoder read
- motor CAN timeout
- startup failure
- internal controller error

## Runtime Surfaces

### Firmware

The controller firmware emits the structured CAN diagnostics and freezes one snapshot on
critical fault entry.

Primary implementation path:

- `software/firmware/joint_controller/src/core1.cpp`

Serial service-only diagnostics also include two bench commands:

- `CMD:CAN_DIAG`
  - legacy motor-bus diagnostic
  - validates MCP2515 loopback, raw TX, and motor replies on `J4`
- `CMD:CAN_DIAG_CROSS`
  - cross-chip stress diagnostic for temporary `J4↔J5` bridging on the same board
  - suspends normal `Host CAN` polling, then sends a bounded frame burst in both directions
  - intended only for lab isolation experiments when proving whether `1 Mbps` failures come
    from the controller runtime or from the external host path

Observed result on `2026-04-10`:

- `CMD:CAN_DIAG_CROSS` passed at runtime on `hip_roll_bench_right` with:
  - `Host CAN = 1 Mbps`
  - `Motor CAN = 1 Mbps`
  - `J4↔J5` bridged via the same CAT5 link used in the bench experiment
  - `512/512` frames each direction, `0` send failures, `0` timeouts, `0` mismatches

That result means the current project default of `Host CAN = 500 kbps` remains an
external-host robustness choice, not a demonstrated limitation of the board-local firmware.

Operational note for the current macOS bench:

- a CANable flashed to `candleLight` may appear in macOS USB inspection while
  `python-can` autodetect still reports no adapters from a sandboxed process
- in that case, the useful path is to force `interface: candle` with the
  device serial/channel explicitly, rather than relying on the repo default
  `slcan` config or on autodetect
- this is a host-tooling quirk of the current Mac bench path, not a controller
  firmware fault

### Flask Host

The Flask host decodes and persists structured diagnostic history per joint.

Relevant files:

- `software/host/can_manager.py`
- `software/host/diagnostic_history.py`

Runtime evidence is stored under:

- `software/host/logs/diagnostic_history/`

### Jetson Runtime

The Jetson controller is the operational collector for integrated experiments.

Relevant files:

- `software/host/jetson_controller/telemetry.py`
- `software/host/jetson_controller/tui.py`
- `software/host/jetson_controller/fsm.py`
- `software/host/jetson_controller/safety.py`

The TUI exposes:

- per-joint diagnostic summary in the `Diag` column
- active and latched fault state for the selected joint
- latest `EVENT_NOTICE`
- health counters and fault epoch

## Diagnostic Scripts (host bench tools)

Repeatable bench tools that drive the CAN diagnostic surfaces above. Run from `software/host`
(`PYTHONPATH="$(pwd)" arch -arm64 .venv/bin/python -m jetson_controller.<script>`).

### Black box — `read_blackbox.py`

Retrieves + decodes the firmware FAULT SNAPSHOT over CAN (query `0x01F` sub `0x00` → meta `0x540`; if
`snapshot_present`, dump sub `0x01` → chunks `0x550` → decoded blob). Shows the freeze event, the active +
latched faults, the per-DOF / per-motor state AT the freeze, and the health counters. Use it whenever a
joint "went wild" or e-stopped and you need to know WHY.

- **KEY GOTCHA:** the snapshot lives in RAM. The MCU stays powered over USB even after the MOTOR power rail
  is cut, so the snapshot SURVIVES a motor-rail e-stop / power cut — **retrieve it BEFORE rebooting or
  USB-power-cycling the board**, or it is lost.

### 250 Hz motion recorder — `capture_hirate_dof1.py`, `capture_holdperturb_dof1.py`

Arms the firmware hi-rate windowed recorder (diag `CTRL 0x05`), runs a motion, then dumps the ~7 s / 1800-
record buffer (q, qdes, dth = outer-PID output, iqA/iqB, motor residuals) for offline analysis.

- `capture_hirate_dof1.py` — a slow-ramp sweep (the stick-slip / smoothness probe).
- `capture_holdperturb_dof1.py` — hold at center + record. Flags: `--hand` (operator hand-vibration with a
  timed GO/STOP signal), `--measured-dt` (toggle the PID measured-dt flag, CAN `0x005`), `--ab` (single-
  connection mid-window A/B toggle).
- **Metric:** report SLIPS/° (burst-segmented), NOT freeze% (a sub-LSB quantization artefact at slow speed).
- **GOTCHAS:** (1) GRACEFUL SHUTDOWN — these de-power the motors BEFORE stopping the host stream, so the
  stream-end never leaves a tensioned cascade that freezes into the overrun oscillation. (2) DE-POWER
  BETWEEN RUNS — a rev_d e-stop cuts GP22 motor power; power-cycle before the next motor run. (3) Do NOT A/B
  back-to-back — the gap / re-startup between two runs is itself a trigger; use the single-connection `--ab`.

### Single-motor loop probes — `capture_veltest_dof1.py`, `capture_postest_dof1.py`

Drive ONE motor by the LKM internal VELOCITY (`0xA2`, diag `0x09/0x0A`) or POSITION (`0xA4`, diag `0x0B`)
loop — joint-encoder-guarded + de-power-on-exit — to measure the motor-internal friction rejection vs the
torque cascade. These are the harness reused for the Loop 2 (motor-position) prototype.

## Recommended Operator Workflow

### Nominal Integrated Bring-Up

1. Start the Jetson controller in CAN-only mode for the intended joint set.
2. Confirm the TUI shows each joint as discovered and diagnostically visible.
3. Verify the `Diag` column is not reporting unexpected active or latched faults before
   enabling motion.
4. Keep serial disconnected unless the CAN path itself is the thing under investigation.

Representative launch commands from `software/host/jetson_controller/`:

```bash
./run_knee_right_can_only.sh
./run_knee_right_ankle_right_can_only.sh
./run.sh --no-serial --preflight-auto \
  --joint ankle_left --joint knee_left --joint hip_left \
  --joint ankle_right --joint knee_right --joint hip_right
```

### When a Fault Happens

1. Treat `FAULT_STATUS` and `EVENT_NOTICE` as the primary record of what happened.
2. Check whether the fault is active, latched, or both.
3. Preserve the session evidence before reconnecting or power-cycling hardware.
4. If a snapshot was frozen, retrieve and persist it through the CAN snapshot path.
5. Use serial only if the host CAN path cannot provide the needed visibility.

### Recovery Discipline

- Clear the operational cause first, not just the symptom.
- Use Jetson recovery paths for nominal `E-stop` / post-`E-stop` handling.
- Do not assume a controller is safe to resume simply because active fault bits cleared;
  latched faults and fault epoch still matter.

## Validation Procedure for Multi-Controller Bring-Up

This procedure is the expected acceptance path for the observability plane.

### Stage 1: One Controller

Goal:

- confirm that CAN-only bring-up is diagnosable without serial
- confirm that one controller writes usable health and event history

Primary operator checklist:

- `software/docs/JETSON_SINGLE_CONTROLLER_BRINGUP_CHECKLIST.md`

Checks:

- `HEALTH_STATUS`, `FAULT_STATUS`, and `EVENT_NOTICE` visible end-to-end
- no unexpected active faults in nominal startup
- JSONL history created under `software/host/logs/diagnostic_history/`
- representative fault class produces snapshot metadata and retrievable dump

### Stage 2: Two Controllers

Goal:

- validate that the operator can distinguish faults and events per controller
- confirm that one controller can expose deep diagnostics without degrading the other

Checks:

- distinct per-joint diagnostic timeline
- no startup ambiguity between controllers
- no regressions in command timing when health plane is always on for both controllers
- fault on one controller does not erase evidence from the other

### Stage 3: Six Controllers

Goal:

- validate lower-body observability at integrated bring-up scale

Checks:

- health plane enabled on all six controllers
- deep diagnostics enabled on one selected controller only
- no need to attach serial to understand startup failures or runtime faults
- no obvious timing or reliability regressions attributable to diagnostics traffic

## Evidence to Preserve

For each validation session, preserve:

- Jetson session log
- per-joint JSONL diagnostic history
- representative TUI screenshot for the session state
- snapshot dump for at least one representative failure mode

## Rules That Should Not Be Violated

- Do not replace structured CAN diagnostics with free-form text logs on CAN.
- Do not require USB serial for nominal integrated debugging.
- Do not enable heavy debug streams on every controller by default.
- Do not treat serial as equivalent to the authoritative integrated record.

## Relationship to Other Documents

- `software/docs/CAN_SYSTEM_ARCHITECTURE.md`
  - authoritative wire-level CAN architecture and protocol documentation
- `software/docs/HARDWARE_VALIDATION_ROADMAP.md`
  - stage-by-stage hardware bring-up gates
- `software/docs/JETSON_SINGLE_CONTROLLER_BRINGUP_CHECKLIST.md`
  - first real hardware validation checklist for CAN-first diagnostics
- `software/docs/SET_IMPEDANCE_OPERATIONAL_GUIDE.md`
  - motion-command semantics for the impedance path

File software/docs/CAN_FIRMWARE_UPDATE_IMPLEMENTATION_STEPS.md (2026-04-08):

# CAN Firmware Update Implementation Steps

**Status:** Draft Working Plan
**Date:** 2026-04-08
**Scope:** Convert the current USB-only firmware update path into a safe CAN-based
update system for RP2350 joint controllers.

---

## 1. Current Starting Point

As of `2026-04-08`, the following foundation is already in place:

- persistent records were moved out of the application growth path
- a linker/build guard protects the reserved NVM region
- legacy persistence migration to the new top-of-flash NVM was validated on real
  hardware
- routine USB reflashing now has a safer storage contract
- `flash_map.h` now defines the final target regions for boot/update, slot A,
  slot B, metadata, and persistent NVM
- firmware update metadata record types and `BootState` enums now exist in code
  with read/append helpers against the dedicated metadata sector
- the firmware now initializes missing update metadata at boot
- boot now performs a minimal metadata reconciliation step for slot-linked images
  (`pending_test -> candidate_running`)
- metadata transition helpers now exist for maintenance enter/exit, abort,
  activate, confirm, and rollback state changes
- dedicated `pico2_slot_a*` / `pico2_slot_b*` linker targets now build
- post-build artifact manifests now emit slot base, image size, and CRC32 for
  runtime and slot images
- slot-target `UF2` artifacts are now repacked from `BIN + slot offset` after
  build, so the final artifact matches the real flash destination
- inactive-slot writer primitives now exist in code for erase, in-order page
  writes, and final image verification
- Host CAN command bindings now exist in firmware for:
  - `GET_INFO`
  - `ENTER_MAINTENANCE`
  - `EXIT_MAINTENANCE`
  - `BEGIN_UPDATE`
  - `END_UPDATE`
  - `VERIFY_UPDATE`
  - `ACTIVATE_SLOT`
  - `CONFIRM_UPDATE`
  - `ABORT_UPDATE`
  - `REBOOT`
- a host updater now exists at `software/host/jetson_controller/fw_update.py`
- real hardware validation now confirmed the full Host-CAN activation flow on a
  Pico 2 / RP2350 controller board:
  - inactive-slot write
  - whole-image verify
  - `ACTIVATE_SLOT`
  - reboot into the candidate slot
  - `CONFIRM_UPDATE`
  - exit from maintenance back to stable runtime

Real hardware evidence from `2026-04-07`:
- target board: `hip_roll_bench_right`, `joint_id=8`
- board UID: `8242201C80B670BF`
- active slot before transfer: `slot A`
- candidate written: `slot B`
- artifact size: `277700` bytes (`pico2_slot_b_debug`)
- result sequence:
  - `VERIFY_OK`
  - `ACTIVATE_OK`
  - `CANDIDATE_BOOT_OK`
  - `CONFIRM_OK`
  - `MAINTENANCE_EXITED`
- final metadata state:
  - `active_slot=2`
  - `pending_slot=0`
  - `boot_state=BOOT_STABLE`
  - `maintenance_active=false`
- elapsed time with safe pacing on `Jetson/SLCAN -> MCP2515`: about `5 minutes`
- rollback under deliberate first-boot non-confirmation was also validated on the
  same board:
  - candidate written: `slot A`
  - candidate reached `CANDIDATE_BOOT_OK`
  - host intentionally skipped `CONFIRM_UPDATE`
  - host forced a second reboot
  - controller returned automatically to stable `slot B`
  - final observed state after `EXIT_MAINTENANCE`:
    - `active_slot=2`
    - `pending_slot=0`
    - `boot_state=BOOT_STABLE`
    - `maintenance_active=false`
- interrupted-update resume was then validated on the same board:
  - host intentionally stopped after committed page `32/1087`
  - controller remained in `BOOT_RECEIVING` for target `slot A`
  - a second host session resumed from `page 33/1087` using
    `FW_UPDATE_PROGRESS.next_page_index`
  - the resumed transfer then completed:
    - `VERIFY_OK`
    - `ACTIVATE_OK`
    - `CANDIDATE_BOOT_OK`
    - `CONFIRM_OK`
    - `MAINTENANCE_EXITED`
  - final observed state after the resumed activation:
    - `active_slot=1`
    - `pending_slot=0`
    - `boot_state=BOOT_STABLE`
    - `maintenance_active=false`
- corrupted-image handling was then validated on the same board:
  - host wrote a `slot B` candidate while intentionally flipping byte offset
    `12345` in flight
  - per-page commits still succeeded, so the failure path exercised the whole-
    image verify step rather than the page CRC guard
  - `VERIFY_UPDATE` returned `IMAGE_CRC_MISMATCH`
  - host cleaned up with `ABORT_UPDATE` followed by `EXIT_MAINTENANCE`
  - stable runtime remained on `slot A`
- power-loss behavior was then validated on the same board on `2026-04-08`:
  - Scenario B: power loss after `VERIFY_OK` but before `ACTIVATE_SLOT`
    returned with stable `slot B`, `pending_slot=0`, and `boot_state=BOOT_VERIFIED`;
    `cleanup-session` then restored `BOOT_STABLE` and exited maintenance
  - Scenario A: power loss during `BOOT_RECEIVING` returned with stable
    `slot B`, `pending_slot=0`, and `boot_state=BOOT_RECEIVING`;
    `cleanup-session` then restored `BOOT_STABLE` and exited maintenance
  - Scenario C: power loss during the first boot of a pending `slot A`
    candidate rolled back automatically to stable `slot B` with
    `pending_slot=0`; the board came back with `maintenance_active=true` and
    required `cleanup-session` only to exit maintenance cleanly
- the board was finally restored to its original stable state:
  - `active_slot=2`
  - `pending_slot=0`
  - `boot_state=BOOT_STABLE`
  - `maintenance_active=false`

What is **not** in place yet:

- packaging the boot/update selector as the standard production flash-base image
  is still a release/integration task
- shared-bus / fleet-update hardening is still future work

Important bench prerequisite:
- before trusting any CAN A/B validation result, make sure the board has a
  current flash-base selector image installed (`pico2_boot_update_debug` on the
  bench, or the matching production selector build)
- if CAN update reaches `ACTIVATE_OK`, then reboots, but the controller stays in
  `BOOT_PENDING_TEST` and never emits `CANDIDATE_BOOT_OK`, suspect a stale
  selector first, not a broken candidate slot image

This means the full Host-CAN update flow is now operational on the bench for
one controller at a time, including rollback after a candidate boot that is not
confirmed, resume after a mid-transfer interruption, and verify rejection of a
corrupted candidate. Single-board power-loss interruption is now also validated
on hardware; the remaining work is production packaging and broader shared-bus
hardening.

Additional bench confirmation on `2026-04-08`:
- after reflashing the flash-base selector image over USB, the
  `fw_update_all` wrapper was also validated on a single board in both
  directions (`slot B -> slot A` and back `slot A -> slot B`)
- this closed the apparent `slot B` activation failure and confirmed that the
  earlier timeout was caused by a stale selector, not by the CAN batch updater

Power-loss execution guide:
- `software/docs/CAN_POWER_LOSS_VALIDATION_RUNBOOK.md`

---

## 2. Non-Negotiable Safety Requirements

The CAN update path must satisfy all of these before being considered usable:

1. the running application is never overwritten in place
2. motion is disabled before update traffic starts
3. one board is targeted at a time by `board_uid`
4. every transferred image is verified before activation
5. first boot of the new image is provisional until explicitly confirmed
6. rollback happens automatically if that first boot does not complete correctly
7. workshop recovery over USB/BOOTSEL or SWD remains possible

If any of these are missing, the system is not safe enough for robot use.

---

## 3. Recommended Execution Order

## Phase 1: Freeze the Final Flash Layout

Goal:
- replace the temporary "single app + top-of-flash NVM" layout with the final
  update-ready layout

Current status:
- region definitions are now centralized in code
- a dedicated boot/update selector image now exists and consumes metadata to
  choose the boot slot at flash base
- runtime boot still consumes metadata for safe initialization and slot-linked
  state reconciliation after selector handoff
- slot linker targets now produce:
  - relocated `ELF`
  - relocated `BIN`
  - post-build `firmware_manifest.json`
  - repacked slot `UF2` from `BIN + offset`

Required outputs:
- a single authoritative `flash_map.h`
- fixed regions for:
  - boot / update region
  - app slot A
  - app slot B
  - persistent NVM
  - reserved tail
- linker guards for each application slot build

Recommended shape:

```text
boot/update region
slot A
slot B
persistent NVM
reserved tail
```

Notes:
- keep the current top-of-flash NVM concept
- do not let slot growth silently eat NVM
- keep enough headroom for firmware growth and metadata

Exit criteria:
- both slot linker targets build cleanly
- slot artifacts expose offset/size/CRC in a machine-readable manifest
- persistent NVM remains outside both slot ranges

Known toolchain caveat:
- the framework still tries its default `ELF -> UF2` conversion first
- for slot-linked images that converter prints an RP2350 address-range error
- the build still succeeds, and the final slot `UF2` is then regenerated
  correctly from the `BIN` artifact in a post-build step

---

## Phase 2: Define Update Metadata

Goal:
- make slot activation and rollback explicit

Current status:
- metadata record layout and boot-state enums are now defined in code
- metadata journaling helpers exist
- boot already initializes missing metadata and performs a minimal
  `pending_test -> candidate_running` reconciliation for slot-linked images
- explicit transition helpers now exist for maintenance, abort, activate,
  confirm, and rollback state changes

Add a small boot metadata record with fields like:
- magic
- version
- active slot
- pending slot
- image size
- image CRC / hash
- boot state (`stable`, `pending`, `rollback_required`)
- boot attempt counter

Behavior:
- current stable image runs from `active_slot`
- after update verification, `pending_slot` is set
- next boot tries `pending_slot`
- only a successful first boot converts `pending_slot` into `active_slot`
- otherwise the system rolls back automatically

Exit criteria:
- metadata can represent stable, pending, and rollback states unambiguously

---

## Phase 3: Add Maintenance / Update Mode

Goal:
- make updates possible only in a safe controller state

Required firmware behavior:
- reject startup sequence during update mode
- reject impedance / motion commands during update mode
- reject calibration writes during update mode
- expose read-only identity and update-status queries

Recommended entry conditions:
- host selects board by `board_uid`
- board acknowledges `ENTER_MAINTENANCE`
- controller confirms:
  - motion disabled
  - startup inactive
  - no calibration operation in progress

Exit criteria:
- the board can enter and leave maintenance mode deterministically
- update mode cannot coexist with motion control

---

## Phase 4: Implement the Inactive-Slot Writer

Goal:
- write a new firmware image into the inactive slot safely

Current status:
- inactive-slot writer primitives now exist in code
- the writer is now reachable from Host-CAN commands and validated on the real
  `Jetson/SLCAN -> MCP2515` transport
- writes are bounded to the inactive slot only
- begin is now rejected unless maintenance mode is active in metadata
- page commits are strict, ordered, and validated by CRC16
- whole-image CRC32 verification is implemented

Requirements:
- page-buffered writes only
- strict offset bounds checking
- no writes outside the inactive slot
- per-page validation
- per-page retry support
- final whole-image verification

Recommended writer behavior:
- reject wrong target UID
- reject writes if maintenance mode is not active
- reject page writes outside declared image size
- stage one flash page in RAM, validate it, then write it
- store received bytes only in the inactive slot
- compute running CRC as pages arrive

Exit criteria:
- a complete image can be written and verified in the inactive slot without
  touching the active slot or NVM
- the writer can then be bound to CAN update commands without changing its
  flash-safety contract

---

## Phase 5: Define the CAN Update Protocol

Goal:
- freeze a simple, explicit wire protocol for host ↔ controller update sessions

Minimum command set:

1. `GET_UPDATE_INFO`
2. `ENTER_MAINTENANCE`
3. `BEGIN_UPDATE`
4. `WRITE_PAGE`
5. `END_UPDATE`
6. `VERIFY_UPDATE`
7. `ACTIVATE_SLOT`
8. `REBOOT`
9. `CONFIRM_UPDATE`
10. `ABORT_UPDATE`

Each session should include:
- target `board_uid`
- target slot
- firmware version
- image size
- image CRC / hash
- page index
- page fragment sequence

Protocol rules:
- one update session per board
- no broadcast firmware writes
- no implicit slot choice
- no implicit reboot on partial transfer

Exit criteria:
- the protocol is documented tightly enough that host and firmware can be
  implemented independently

Reference:
- `software/docs/CAN_FIRMWARE_UPDATE_PROTOCOL_SPEC.md`

Current status:
- the protocol is now implemented for the full single-board activation flow on
  the current bench path
- real hardware exposed a transport requirement that is now encoded in the host
  updater:
  - explicit control-burst pacing
  - explicit `PAGE_BEGIN -> frag0` delay
  - explicit fragment pacing on `SLCAN -> MCP2515`
- without that pacing, real hardware produced:
  - `INVALID_STATE` during `BEGIN_UPDATE`
  - `FRAG_INDEX_MISMATCH` mid-transfer

---

## Phase 6: Build the Host Update Tool

Goal:
- make Jetson able to perform deterministic firmware updates over CAN

Host tool responsibilities:
- discover board update info
- select exact target board by `board_uid`
- send `ENTER_MAINTENANCE`
- stream image pages with retry / timeout handling
- request verification
- request activation + reboot
- wait for `CANDIDATE_BOOT_OK`
- report success / rollback / timeout clearly

Recommended first form:
- a CLI tool before any UI integration

Why:
- easier to debug
- easier to log
- easier to use in controlled bench tests

Exit criteria:
- one board can be updated from Jetson over CAN end-to-end with logs

Current status:
- achieved on `2026-04-07` for `hip_roll_bench_right`
- final observed state was:
  - `active_slot=2`
  - `pending_slot=0`
  - `boot_state=BOOT_STABLE`
  - maintenance exited successfully
- the CLI now also supports explicit validation helpers for bench work:
  - intentional interruption after N pages
  - resume from `FW_UPDATE_PROGRESS.next_page_index`
  - intentional byte corruption with expected verify-failure cleanup

---

## Phase 7: Validate Failure Cases

Goal:
- prove the updater is robust under realistic failures

Failure cases that must be tested:
- wrong target UID
- page loss / retry
- corrupted image CRC
- power loss during transfer
- power loss after verification but before activation
- power loss during first boot of candidate image
- candidate image boots but never sends `CANDIDATE_BOOT_OK`

Expected outcomes:
- active slot remains bootable unless explicit activation succeeds
- corrupted candidate never becomes active
- first-boot failure returns to previous stable slot
- candidate boot without host confirmation remains provisional and rolls back on
  the next reset

Exit criteria:
- rollback is demonstrated, not assumed

---

## 4. Practical Bench Plan

Recommended bench order:

1. single Pico 2 on controller PCB
2. one CAN link from host adapter to Host CAN
3. no motors required for the first update-protocol bring-up
4. validate update transport and slot switching first
5. only later repeat on a controller with real motors/encoders connected

Reason:
- update architecture should be proven before mixing in actuator-side failure modes

---

## 5. What Not To Do

Do **not**:
- overwrite the running app in place
- tie update identity only to joint ID
- allow updates while motion commands are accepted
- depend on current `picotool` erase behavior as part of the safety model
- treat "boots once" as equivalent to "update succeeded"

These choices would create avoidable brick risk.

---

## 6. Definition of Done

The CAN update path is done only when all of the following are true:

- slot-based update path exists
- rollback exists
- maintenance mode exists
- host tool exists
- one-board bench update succeeds repeatedly
- power-loss and corrupted-image tests pass
- persistent NVM survives all update scenarios
- workshop recovery instructions are documented

Before that point, CAN reflashing should remain a development feature only.

Current overall status on `2026-04-08`:
- satisfied now:
  - slot-based update path exists
  - maintenance mode exists
  - host tool exists
  - one-board bench update succeeds end-to-end
  - rollback after deliberate non-confirmed candidate boot is demonstrated
  - interrupted-update resume is demonstrated
  - corrupted-image rejection at whole-image verify is demonstrated
  - single-board power-loss behavior is demonstrated across all three planned scenarios
  - persistent NVM is separated from slot writes
- still open:
  - recovery procedure hardening
  - production packaging of the flash-base selector image
  - shared-bus / fleet-update hardening

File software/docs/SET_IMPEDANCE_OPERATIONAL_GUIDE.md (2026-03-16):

# SET_IMPEDANCE Operational Guide

## Summary

`SET_IMPEDANCE` is not a direct position-step controller.

The host sends:
- `q_target`: joint goal
- `dq_target`: cruise speed magnitude
- `stiffness`, `tau_ff`, outer `Kp/Ki/Kd`, inner `Kp/Ki/Kd`

The RP2350 converts each command into a single overwrite-only local segment:
- no command queue
- last command wins
- local linear interpolation at the firmware control rate
- existing incremental PID cascade remains the control law

This keeps the reactive command interface of impedance mode while preserving smooth local trajectory generation in firmware.

## Runtime Semantics

For each DOF the firmware keeps a rolling segment state:

- `q_start`
- `q_goal`
- `q_ref`
- `dq_ref`
- `speed_abs`
- `t_start_ms`
- `t_arrival_ms`
- `active`
- `initialized`

On every accepted `SET_IMPEDANCE` command:

1. The firmware samples the current local reference.
2. That sampled `q_ref_now` becomes the start of the next segment.
3. `q_target` becomes the new goal.
4. `dq_target` is interpreted as speed magnitude.
5. Direction is derived from `q_goal - q_ref_now`.
6. The firmware computes a linear local segment and tracks it at the outer-loop rate.

If the goal is already within the hold epsilon, the segment is inactive and the DOF holds the goal immediately.

## Control Stack

`SET_IMPEDANCE` uses the existing cascade control structure:

1. Firmware generates `q_ref, dq_ref`.
2. Outer incremental PID tracks `q_ref`.
3. `theta_0` is computed from `q_ref`, not from the final goal.
4. Tendon/motor references are built with the usual cascade formula and commanded stiffness.
5. Inner incremental motor PID tracks the motor references.
6. `tau_ff` is added as feedforward on top of the existing friction feedforward.

`Ki` now travels with `SET_IMPEDANCE` too:

- outer `Kp/Ki/Kd` override the active joint-space PID while impedance mode is active
- inner `Kp/Ki/Kd` override both motor PIDs while impedance mode is active
- on impedance exit, the saved default PID values are restored

## Operational Tuning and Contact Response

### What `tau_ff` is for

`tau_ff` is an additive feedforward torque term sent by the host.

- `tau_ff > 0` biases torque toward the agonist direction
- `tau_ff < 0` biases torque toward the antagonist direction
- it is applied on top of the local friction feedforward already running in firmware

Use `tau_ff` for:

- known static or slowly varying loads
- gravity compensation
- intentional contact where a small bias torque is desired
- reducing steady-state tracking effort under predictable load

Do **not** use `tau_ff` as the primary response to an unexpected collision. It adds push; it does not make the joint compliant.

### Parameters to change first during contact or collision

If the Jetson detects unexpected contact, the first parameters to change are:

1. `q_target` — stop advancing, hold near the current angle, or retreat
2. `dq_target` — reduce approach speed
3. `stiffness` — reduce co-contraction
4. outer `Kp/Ki/Kd` — usually reduce `Kp`, and reduce or disable `Ki`

Only after these should the host consider changing inner gains. In most cases, `tau_ff` should be driven to `0` during collision handling.

### Recommended collision-safe profile

For a conservative collision response:

- move `q_target` toward the current measured angle or toward a retreat target
- lower `dq_target`
- lower `stiffness`
- lower outer `Kp`
- lower or zero outer `Ki`
- keep `tau_ff = 0`

This yields a softer, more compliant response without weakening the inner motor tracking loop unnecessarily.

### Recommended nominal profile

For normal tracking under predictable load:

- `q_target` and `dq_target` define the desired motion
- `stiffness` defines co-contraction
- outer and inner PID gains define tracking behavior
- `tau_ff` remains optional and should be introduced only when load compensation is needed

## Safety and State

- `dq_target = 0` is only valid for hold commands near the current position.
- Watchdog timeout invalidates the rolling segment and falls back to hold.
- `IMPEDANCE_CTRL disable` restores the saved PID parameters and falls back to hold.
- Safety-stop paths clear the rolling segment and exit impedance mode without re-arming it.
- `JOINT_STATE.holding = 1` means the rolling segment is inactive for that DOF.

## Host Guidance

- A 50 Hz host stream is acceptable for first experiments.
- The firmware interpolates locally at the control-loop rate, so host commands do not need to enumerate micro-steps.
- If the Jetson changes its mind because of collision or balance recovery, it simply sends a new `SET_IMPEDANCE`; the previous local segment is overwritten.

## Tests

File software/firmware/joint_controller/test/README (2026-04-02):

This directory is reserved for PlatformIO-native firmware tests.

The current repository relies primarily on host-side tests plus hardware validation runs. Add PlatformIO tests here when a firmware behavior can be exercised reliably in isolation.

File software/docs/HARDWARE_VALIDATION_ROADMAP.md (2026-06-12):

# Hardware Validation Roadmap

> **Status:** Active
> **Created:** 2026-03-23
> **Scope:** From single-joint baseline to dual-leg assembly

---

## Principles

1. **Every level has measurable exit criteria.** Do not move to the next level until they are met.
2. **Multi-DOF before multi-joint.** The most critical architectural jump is `MAX_DOFS > 1` on the same controller, not the number of joints.
3. **Webapp for single-controller commissioning, Jetson for multi-controller coordination.**
4. **One leg before two.** The second leg is a replica, not an experiment.

---

## L1 — Knee Single (1 DOF, 1 controller)

**Status:** ✅ Closed as architecture baseline

**What is validated:**
- Impedance control (50Hz move stream, sinusoidal oscillation)
- Stable hold with outer Ki freeze
- RevTrack in actuator domain (0x92/0xA1 domain mismatch fix)
- DIAG_HOLD unified telemetry (EMA bias, torque ratio, motor residual)
- Retension probe with CAN publish
- Webapp move/hold/oscillation path complete
- Configurable watchdog (hold + stream)
- Stable SLCAN listener (`timestamp` crash fix)

**What is NOT closed (and is not required to move up):**
- Active tension trim (Phase 2) — remains dry-run
- Final slack detector — thresholds not yet validated on clean data
- Final host policy for auto-retension

**Exit criteria:** ✅ All met
- [x] Hold at 0°, 30°, 60°, 90° without watchdog timeout
- [x] Stable oscillation for at least 60s
- [x] RevTrack without persistent warnings (post-fix)
- [x] DIAG_HOLD visible in webapp with consistent signals
- [x] No SLCAN crash under normal load

---

## L2 — Ankle Single (2 DOF, 1 controller)

**Status:** ✅ Closed as architecture baseline

**Goal:** Validate firmware and webapp with 2 DOF on the same controller. First intra-joint coordination test.

**Platform:** Webapp

**What it tests beyond L1:**
- `dof_state[]` with 2 elements active simultaneously
- Independent hold/move per DOF (e.g. DOF0 holding, DOF1 moving)
- DIAG_HOLD for multiple DOFs (UI cards, chart with DOF selector)
- 4 motors on the same motor CAN bus (vs 2 for the knee)
- Pretension/recalc across 2 DOFs — sequencing and timing
- Smart impedance buttons with multi-DOF mapping

**Specific risks:**
- Motor CAN bus contention: 4 motors at 50Hz = 200 frames/s for torque command+response alone
- Mechanical interaction between the 2 DOFs (one DOF moves the other's load)
- Init/homing sequence: does DOF order matter?

**Exit criteria:** ✅ All met on the `ANKLE_RIGHT` bench
- [x] Init + homing of both DOFs without errors
- [x] Stable hold on both DOFs simultaneously
- [x] Move DOF0 while DOF1 is holding — no significant disturbance on DOF1
- [x] Consistent DIAG_HOLD for both DOFs
- [x] Oscillation / move of one DOF without regressions on the other
- [x] No CAN error/overrun on the validated nominal run
- [x] Stable and repeatable recalc offset / startup sequence

**Practical note:**
- `ANKLE_LEFT` is not available on the current bench
- L2 closure is therefore on the `ANKLE_RIGHT` profile, sufficient as a single-controller 2-DOF architecture baseline

---

## L3 — Hip Single (3 DOF, 1 controller)

**Status:** ⏸ Blocked by hybrid-model refactor

**Goal:** Validate the heaviest single-controller case: 3 DOF, 5 motors.

**Platform:** Webapp

**Current blocker:**
- the real `HIP` is not a uniform `3 DOF / 6 motors / 2 motors per DOF` joint
- the correct model is a hybrid joint:
  - 2 tendon-driven antagonistic DOFs
  - 1 direct-drive single-motor roll DOF
- before the single HIP test, the software abstraction must be fixed, as described in [HIP_HYBRID_DOF_SPEC.md](software/docs/HIP_HYBRID_DOF_SPEC.md)

**Bench note (2026-04-09):**
- the direct-drive `hip_roll_bench_right` sub-case has already been brought up
  on the Jetson bench and moved successfully at `±5°`, `±10°`, `±15°`, with
  stable hold at `0°`
- this does not unlock full `L3` yet, but it de-risks the isolated roll path
  and confirms that single-DOF physical bring-up is practicable
- still open:
  - destructive reference test (`REFERENCE_REQUIRED -> Set Reference -> reboot`)
  - final cleanup of CAN warnings under motion
  - the recent `MOTOR_TIMEOUT` block seen on cold-start after `PRETENSION_ALL`
    was due to a bench power-supply issue; after the hardware fix the
    cold-start passes again, and the remaining useful software improvement is
    that the host reports it explicitly instead of degrading into
    `POSITION_RANGE`
- `LOOP_OVERRUN` on the roll sub-case is no longer the main blocker: the
  firmware debounce/hysteresis pass brought it to `0` in the validated `20 s`
  runs (`hold`, `±5°`, `±10°`, `±15°`)
- the most credible residual warning remains `MOTOR_CAN_WARN`; `HOST_CAN_WARN`
  has dropped but is still partially contaminated by the Jetson bench `slcan`
  path
- decision frozen after the `2026-04-09` bench campaign: `Host CAN` defaults
  to `500 kbps`; `1 Mbps` remains a diagnostic override until the final
  harness is validated
- additional confirmation from `2026-04-10`: with `J4↔J5` jumpered on the same
  board, the cross-chip test at `1 Mbps` passed both at boot (`1024/1024`
  frames per direction) and at runtime in the full firmware via
  `CMD:CAN_DIAG_CROSS` (`512/512` frames per direction, `0` errors)
- so the operational downgrade to `500 kbps` is not required by the
  controller's firmware loop, but remains a prudent choice for the current
  external host path until the final harness is validated

**Power board note (2026-06): `rev_d_power` bench-validated end-to-end**
- the first `joint_controller_board_rev_d_power` board (first fabricated
  article) was validated on the `hip_roll_bench_right` bench (joint 8,
  direct-drive)
- chain covered: bare board → continuity/smoke test → 5V buck rail + 3V3_AUX
  LDO → TPS2492 hot-swap + back-to-back FET path → HEALTH_STATUS telemetry
  (frame `0x82`) decoded end-to-end at the host → `FAULT_N` handling
  (active-low, edge counter) → closed-loop control of a real motor →
  safety-limit enforcement
- closed-loop: `+5°` nudge with `0.08°` steady-state tracking error, loop
  ~350µs (2000µs budget), `0` CAN errors, no motor timeout
- safety limit: `+40°` command clamped by firmware to `±38.5°` (fixed 1.5°
  margin inside the hard limit for direct-drive joints, tendon equations not
  available) — graceful behavior (WARN + clamp, no fault/E-stop)
- hardware confirmations: `PWRGD_N`/`FAULT_N` active-low polarities correct;
  `VIN_RAW_MON` 82k/8.2k divider accurate (2.18V at 24V); 100k pulldown on
  `SAFETY_EN` (OFF by default); auto-enable at boot when power is present —
  intentional behavior retained
- full evidence in
  [BENCH_VALIDATION_REPORT.md](../../hardware/electronics/joint_controller_board/rev_d_power/BENCH_VALIDATION_REPORT.md)
- **still open on the power board:**
  - Phase 7 high-current stress (22A continuous / ~38A peak) with a battery or
    large PSU + external 30A ATO fuse + real load — not yet executed
  - real TPS2492 overcurrent latch-off not yet exercised (requires a stiff
    power supply)

**What it tests beyond L2:**
- MAX_DOFS=3 all active
- 5 motors on the same motor CAN bus (~250 frames/s torque loop)
- Outer PID for 3 concurrent DOFs
- DIAG_HOLD for 3 DOFs — maximum telemetry load per controller
- Control loop timing: 2 + 2 + 1 active motors with a tendon/direct-drive mix = critical cycle time

**Specific risks:**
- Control loop not completing within 2ms with 5 motors (2 tendon pairs + 1 direct-drive)
- Saturated motor CAN bus: 5 motors × 50Hz × 2 (cmd+resp) = 500 frames/s
- Pretension/recalc on 2 tendon DOFs + direct-drive roll startup: total time, stability
- Heat: 5 motors active in hold generate heat — thermal throttling?

**Exit criteria:**
- [ ] Init + homing of all 3 DOFs without errors
- [ ] Stable hold on 3 DOFs simultaneously for 120s
- [ ] Control loop rate stable at 500Hz (jitter measured via logs)
- [ ] No CAN error/overrun on the motor bus with 5 motors
- [ ] DIAG_HOLD for all 3 DOFs: consistent signals
- [ ] Motor temperature stable after 5 min of hold (no thermal runaway)
- [ ] Move one DOF while the other 2 are holding — no disturbance

---

## L3.5 — Protocol Freeze Gate

**Status:** ✅

**Goal:** Freeze the host↔controller CAN protocol before developing the final Jetson path. Avoids testing L4 against a moving protocol.

**To freeze:**
- [x] Command cadence: 50Hz confirmed as production target
- [x] Watchdog policy: nominal value, relaxed webapp value, configurable hold watchdog
- [x] Production vs debug telemetry: separate production/documentation streams
- [x] Sequence counters: format and position documented where used
- [x] Nominal error handling: startup, already-ready resume, post-`E-stop` same-session
- [x] JOINT_STATE: production content and rate confirmed
- [x] DIAG_HOLD / RPROBE: treated as non-critical telemetry at the production freeze

**Deliverable:** "Protocol v1.0" section in CAN_SYSTEM_ARCHITECTURE.md with all values frozen and versioned.

**Exit criteria:**
- [x] Protocol freeze document approved
- [x] No "TBD" fields in the frozen production frames
- [x] Jetson controller software can be developed against this specification without ambiguity

---

## L4 — Two-Controller Bench (Jetson)

**Status:** 🟡 Bench-validated, extended recovery edge cases still pending

**Goal:** First coordinated multi-controller validation via Jetson. Knee + Ankle on the bench (not mechanically assembled).

**Platform:** Jetson (direct CAN)

**Note:** The Jetson software developed here must be the **final path**, not a throwaway prototype. 50Hz scheduler, multi-controller commanding, watchdog discipline, structured logging of jitter/latency/error counters.

**What it tests:**
- Jetson controller software: 50Hz command loop for 2 controllers
- Host CAN bus with 2 active joints: commands + feedback + telemetry
- Time synchronization of commands across joints
- Tight watchdog (100ms) with Jetson — feasible?
- Recovery: what happens if a controller stops responding?

**Prerequisites:**
- **L3.5 protocol freeze completed**
- Working Jetson controller software for sending impedance commands
- At least knee + ankle controllers flashed and individually functional
- Single-controller CAN-first bring-up executed with checklist:
  [JETSON_SINGLE_CONTROLLER_BRINGUP_CHECKLIST.md](software/docs/JETSON_SINGLE_CONTROLLER_BRINGUP_CHECKLIST.md)

**Metrics to collect:**
- Actual Jetson loop rate (target 50Hz)
- Command→response latency per joint
- Skew between commands to the 2 controllers (target < 1 period = 20ms)
- CAN bus utilization (frames/s, % bandwidth)
- CAN error counters (overrun, lost arbitration, bus-off)
- Watchdog warnings/timeouts

**Exit criteria:**
- [ ] Jetson sends commands to 2 controllers at 50Hz for 30 min without timeouts
- [ ] Skew between commands to the 2 controllers < 20ms (1 period)
- [ ] No CAN error/overrun on the host bus
- [ ] Recovery from controller restart: Jetson detects and re-initializes
- [ ] Recovery from Jetson restart: controllers go safe (watchdog)
- [ ] CAN bus utilization < 70% (headroom for telemetry)

**Evidence already collected on the bench (2026-03-31):**
- `KNEE_RIGHT + ANKLE_RIGHT` correctly discovered on the same bus
- nominal multi-controller startup: valid
- manual home and nudge on all DOFs: valid
- automatic `knee + ankle` exercise for 60s and 300s: valid
- `INVALID CAN READ = 0`, `missed 0xA1 = 0`, `RESYNC = 0`, `PROFILING OVER BUDGET = 0` in the validated clean runs
- post-`E-stop` within the **same Jetson session**: recovery valid with:
  - selective `PRETENSION_ALL`
  - `RECOVERY_SETTLE`
  - resume on the current pose

**Still open on L4:**
- automatic recovery if the Jetson process is restarted after `E-stop`
- long session with formally documented close-out criteria

---

## L5 — Three-Controller Stress Test (Jetson)

**Status:** 🔲

**Goal:** Validate CAN throughput and Jetson software with the full half-leg load (hip + knee + ankle).

**Platform:** Jetson (direct CAN), 3 controllers on the bench

**CAN profiles to define:**

| Profile | Commands | Feedback | Telemetry | Estimated usage |
|---|---|---|---|---|
| **Production** | 50Hz impedance per joint | 50Hz encoder stream | DIAG_HOLD 0.3Hz, RPROBE on-demand | ~baseline |
| **Debug** | as production | as production | + verbose serial log | ~+30% |
| **Stress** | as production | as production | + DIAG_HOLD 2Hz, forced probes | ~+50% |

**Bandwidth estimate (order of magnitude, not a design value):**

The real cost of a standard CAN frame depends on payload, bit stuffing and
inter-frame spacing. 120 bits/frame is a lower bound; a conservative budget
is ~130-150 effective bits/frame.

At 500 kbps with ~140 real bits/frame: ~3570 frames/s practical max.

- Production estimate: 3 joints × (50 cmd + 50 resp + 50 encoder + 10 joint_state) = 480 frames/s → ~13%
- With debug telemetry: +50 frames/s → ~15%

Conclusion: the physical bus **very likely** holds. But it must be **proven
with instrumented testing** (L5), not assumed. The real limit will be the host
software (scheduling jitter, RX/TX contention, queue management).

**Metrics to collect:**
- All of L4's, plus:
- Per-joint jitter distribution (histogram)
- Worst-case loop time
- Recovery time after global E-Stop
- Session duration without degradation

**Exit criteria — nominal:**
- [ ] 3 controllers active for 60 min without CAN errors
- [ ] Jetson loop rate stable at 50Hz (jitter < 5ms p99)
- [ ] No detectable frame loss (sequence counter check)
- [ ] E-Stop → all controllers safe within 100ms
- [ ] Single controller restart → Jetson detects and re-initializes within 2s
- [ ] "Production" profile stable without CAN overrun
- [ ] "Stress" profile: maximum sustainable threshold identified

**Exit criteria — degraded mode:**
- [ ] 1 controller slowed down (responses at 25Hz instead of 50Hz) → the other 2 remain stable
- [ ] Loss of debug telemetry (DIAG_HOLD/RPROBE) → control loop unaffected
- [ ] Partial restart of 1 controller during operation → Jetson isolates the fault and the other 2 continue
- [ ] Temporary host jitter (50ms spike) → no watchdog timeout on the controllers
- [ ] Bus error burst (10 corrupted frames) → automatic recovery without human intervention

---

## L6 — Half Leg Assembly (Jetson)

**Status:** 🔲

**Goal:** First complete mechanically assembled leg. Validation under real load.

**Platform:** Jetson

**Prerequisites:**
- L3 (hip single) completed
- L5 (three-controller stress) completed
- Mechanical structure assembled (hip → knee → ankle)
- Final CAN wiring (lengths, terminations)

**What it tests:**
- Real gravitational load distributed across 3 joints
- Mechanical interaction between joints (moving the hip changes the load on knee and ankle)
- Multi-joint trajectory planning: real coordinated movements
- Wiring and connectors under mechanical stress
- Real power consumption with all motors under load

**Minimum tests:**
1. Sequential init + homing (hip → knee → ankle)
2. Stable hold in neutral posture for 10 min
3. Simple coordinated movement: "bend the leg" (knee flex + ankle dorsiflexion)
4. Coordinated movement under load: leg suspended with a weight
5. Recovery test: E-Stop during movement → safe stop
6. Long session: 30 min of mixed movements

**Exit criteria:**
- [ ] Repeatable full homing (3/3 successes)
- [ ] 10 min hold without watchdog timeout or CAN error
- [ ] Smooth 3-joint coordinated movement (no jerk between phases)
- [ ] Safe E-Stop from any state
- [ ] Wiring: no intermittent contact after 100 flexion cycles
- [ ] Motor temperature stable after 15 min of mixed activity
- [ ] No performance degradation over a long session (30 min)

---

## L7 — Two Legs (Jetson)

**Status:** 🔲

**Goal:** Complete 12-DOF system (6 joints, 12 motors).

**Platform:** Jetson

**Prerequisites:**
- L6 (half leg) successfully completed
- Second leg assembled
- CAN bus: evaluate whether 2 separate buses (1 per leg) are needed or 1 bus suffices

**Open architectural question: CAN topology**

| Option | Pros | Cons |
|---|-----|---|
| 1 host bus | Simple, less hardware | 960 frames/s, ~23% bandwidth — feasible |
| 2 host buses (L/R) | Fault isolation, double bandwidth | Requires a second CAN interface on the Jetson |

Decision deferred until after L5 data. Don't choose out of abstract prudence — measure first.

**Minimum tests:**
1. Init both legs sequentially
2. Symmetric bilateral hold
3. Mirrored movement (both legs do the same)
4. Independent movement (one leg moves, the other holds)
5. Stress test: continuous alternating movements for 60 min
6. Fault injection: disconnect one controller and verify the other leg stays safe

**Exit criteria:**
- [ ] Repeatable init of 6 controllers
- [ ] 15 min bilateral hold without errors
- [ ] Smooth 12-DOF coordinated movement
- [ ] Fault isolation: loss of 1 controller does not impact the other leg
- [ ] 60 min long session without degradation
- [ ] CAN bus utilization documented and below 60%

---

## Timeline Summary

```
L1    Knee single        ✅  Closed (baseline)
L2    Ankle single       ✅  Closed (baseline)
L3    Hip single         ⏸  Blocked by hybrid model
L3.5  Protocol freeze    ✅  Closed
L4    2-ctrl bench       🟡  Bench-validated, extended recovery pending
L5    3-ctrl stress      🔲  After L4
L6    Half leg           🔲  After L5
L7    Two legs           🔲  After L6
```

**Possible parallelism:**
- L3 (HIP) is blocked by an architectural refactor, not by CAN/Jetson availability
- L3.5 is closed and can be used as a stable baseline
- L4 already has bench evidence, but should not be "closed" yet without resolving the remaining recovery edge cases
- L5 requires:
  - L4 consolidated
  - or an explicit decision to use the current protocol as a temporary baseline for stress testing

---

## Recommended Next Steps (2026-03-31)

Recommended order, given the actual bench state:

1. **Freeze `KNEE_RIGHT + ANKLE_RIGHT` as the Jetson regression bench**
   - stop using this bench for exploratory refactors
   - use it to verify that future changes do not break:
     - nominal startup
     - manual home / nudge
     - automatic exercise
     - post-`E-stop` recovery within the same Jetson session

2. **Close `L3.5 Protocol Freeze`**
   - the evidence collected on `knee + ankle` is already sufficient to freeze:
     - command cadence
     - watchdog policy
     - nominal startup path
     - same-session post-`E-stop` recovery path
     - minimum production telemetry set
   - this is the next real documentation gate

3. **Open the `HIP` refactor as a separate track**
   - do not use the `knee + ankle` bench to "simulate" the `HIP`
   - implement the hybrid model instead, as per [HIP_HYBRID_DOF_SPEC.md](software/docs/HIP_HYBRID_DOF_SPEC.md)

4. **Only after the `HIP` refactor, do the first single `HIP` bring-up**
   - not before
   - the dominant risk now is no longer CAN/Jetson: it is the wrong software model of the hybrid joint

5. **Defer the "Jetson restart after E-stop" case to a later bugfix**
   - useful, but it does not block the current milestone
   - it must not delay `L3.5` or the `HIP` refactor

---

## Appendix: CAN Rate Profile Reference

To support sizing at each level.

**Per single joint (1 controller):**

| Stream | Direction | Rate | Frames |
|---|---|---|---|
| Impedance command | Host→Controller | 50 Hz | 1 |
| Torque cmd+resp (per motor) | Controller↔Motor | 50 Hz | 2 × N_motors |
| Encoder stream | Controller→Host | 50 Hz | 1 |
| JOINT_STATE | Controller→Host | ~10 Hz | 1 |
| DIAG_HOLD | Controller→Host | 0.3 Hz | 2 |
| RPROBE | Controller→Host | on-demand | 1 |

**Host bus (Host↔Controller) for N joints:**
- Command: N × 50 = frames/s
- Encoder: N × 50 = frames/s
- JOINT_STATE: N × 10 = frames/s
- Telemetry: ~N × 1 = frames/s
- **Total: ~111 × N frames/s**

| Config | N | Host bus frames/s | % of ~3570 practical max |
|---|---|---|---|
| Knee | 1 | ~111 | ~3% |
| Knee+Ankle | 2 | ~222 | ~6% |
| Half leg | 3 | ~333 | ~9% |
| Two legs | 6 | ~666 | ~19% |

Conservative estimates (order of magnitude). The physical bus probably holds;
the bottleneck will be the host software. To be verified with instrumented
testing (L5).

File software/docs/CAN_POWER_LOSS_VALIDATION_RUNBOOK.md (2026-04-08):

# CAN Power-Loss Validation Runbook

**Status:** Bench Runbook And Result  
**Date:** 2026-04-08  
**Scope:** Validate the only major unproven fault path remaining in the single-board
Host-CAN firmware update flow: power interruption at critical phases.

---

## 1. Purpose

As of `2026-04-08`, the following are already validated on real hardware:

- write + verify over Host CAN
- activate + confirm over Host CAN
- rollback after deliberate non-confirmation
- interrupted-update resume from `FW_UPDATE_PROGRESS.next_page_index`
- corrupted-image rejection with `IMAGE_CRC_MISMATCH`

The remaining unproven area was **power loss**.

This runbook defines how to test it on one RP2350 joint-controller board without
guesswork.

Executed result on `2026-04-08`:

- target board: `hip_roll_bench_right`
- `joint_id=8`
- board UID: `8242201C80B670BF`
- stable slot before campaign: `slot B` (`active_slot=2`)
- Scenario B passed:
  - after power restore, the board returned in `BOOT_VERIFIED + maintenance`
  - `cleanup-session` restored `BOOT_STABLE` and exited maintenance
- Scenario A passed:
  - after power restore, the board returned in `BOOT_RECEIVING + maintenance`
  - `cleanup-session` restored `BOOT_STABLE` and exited maintenance
- Scenario C passed:
  - after the double power cut during first candidate boot, the board returned
    on the previous stable slot with `pending_slot=0`
  - the board came back in stable runtime but with maintenance still active
  - `cleanup-session` then exited maintenance cleanly
- final board state after the whole campaign:
  - `active_slot=2`
  - `pending_slot=0`
  - `boot_state=BOOT_STABLE`
  - `maintenance_active=false`

---

## 2. Preconditions

- use a single controller board on the bench
- no motion should be active
- motors/actuators should be electrically safe or disconnected
- use a controllable power switch so power can be removed and restored quickly
- keep USB serial and Host CAN connected if possible
- use the current host tool:
  - `software/host/jetson_controller/fw_update.py`

Recommended starting point:

- board stable on a known slot
- no pending update state
- maintenance not active

Check that before every scenario:

```bash
cd software/host
python3 -m jetson_controller.fw_update --joint hip_roll_bench_right --info-only
```

If the controller is not clean before starting:

```bash
cd software/host
python3 -m jetson_controller.fw_update --joint hip_roll_bench_right --cleanup-session
```

---

## 3. Artifact Selection

Choose the inactive-slot artifact based on the current active slot.

If `active_slot=2` (`slot B`), use:

```bash
../firmware/joint_controller/.pio/build/pico2_slot_a_debug/firmware_manifest.json
```

If `active_slot=1` (`slot A`), use:

```bash
../firmware/joint_controller/.pio/build/pico2_slot_b_debug/firmware_manifest.json
```

---

## 4. Common Evidence To Capture

For every scenario, save:

- initial `--info-only` output
- the exact command used
- timestamp of power removal
- timestamp of power restoration
- first `--info-only` output after power returns
- final `--info-only` output after any cleanup
- whether the stable slot changed
- whether maintenance stayed active
- whether cleanup was required

---

## 5. Scenario A: Power Loss During `BOOT_RECEIVING`

### Goal

Prove that a mid-transfer power cut does not damage the stable image or persistent
NVM.

### Procedure

1. Check clean starting state with `--info-only`.
2. Start a normal write to the inactive slot, without `--activate`:

```bash
cd software/host
python3 -m jetson_controller.fw_update \
  --joint hip_roll_bench_right \
  --manifest <inactive-slot-manifest>
```

3. Remove power while pages are still being written.
4. Restore power.
5. Query controller state:

```bash
cd software/host
python3 -m jetson_controller.fw_update --joint hip_roll_bench_right --info-only
```

6. If the controller reports `BOOT_RECEIVING`, `BOOT_VERIFIED`, or maintenance
   still active, recover it:

```bash
cd software/host
python3 -m jetson_controller.fw_update --joint hip_roll_bench_right --cleanup-session
```

7. Query final state again with `--info-only`.

### Pass Criteria

- final stable slot is unchanged from the initial slot
- `pending_slot=0`
- maintenance is off after cleanup
- controller is reachable over CAN
- no persistence loss is observed

### Failure Criteria

- controller does not boot or does not answer on CAN
- active slot changes unexpectedly
- metadata cannot be cleaned back to a stable state

---

## 6. Scenario B: Power Loss After `VERIFY_OK` But Before `ACTIVATE_SLOT`

### Goal

Prove that a verified but not activated candidate does not become active after a
power cut.

### Procedure

1. Check clean starting state with `--info-only`.
2. Run a full write + verify to the inactive slot, without `--activate`.
3. When the command exits after `VERIFY_OK`, remove power.
4. Restore power.
5. Query controller state with `--info-only`.
6. If maintenance or verified state persisted, run `--cleanup-session`.
7. Query final state again.

### Pass Criteria

- final active slot is still the original stable slot
- `pending_slot=0`
- candidate did not become active without explicit activation

### Failure Criteria

- candidate becomes active after reboot even though `ACTIVATE_SLOT` was never sent
- controller cannot be recovered with `--cleanup-session`

---

## 7. Scenario C: Power Loss During First Boot Of Candidate

### Goal

Prove that a candidate interrupted before confirmation does not replace the
previous stable slot.

### Preparation

1. Write + verify the inactive slot, without `--activate`.
2. Mark the candidate pending test, but do not reboot yet:

```bash
cd software/host
python3 -m jetson_controller.fw_update \
  --joint hip_roll_bench_right \
  --manifest <inactive-slot-manifest> \
  --activate-only
```

At this point the controller should report `pending_slot=<candidate>` and
`boot_state=BOOT_PENDING_TEST`.

### Procedure

1. Remove and restore power once to start the first candidate boot.
2. Remove power again during that candidate startup window, before any operator
   confirmation is issued.
3. Restore power.
4. Query controller state with `--info-only`.
5. If the controller is already back on the original stable slot with
   `pending_slot=0`, record that as a pass.
6. If the controller comes back in an intermediate state, capture the evidence
   first, then run:

```bash
cd software/host
python3 -m jetson_controller.fw_update --joint hip_roll_bench_right --cleanup-session
```

7. Query final state again with `--info-only`.

### Pass Criteria

- previous stable slot remains or becomes active again
- candidate is not left confirmed
- final state can be returned to `BOOT_STABLE`

### Failure Criteria

- candidate becomes active without a deliberate confirmation
- controller bricks or stops answering on CAN
- rollback does not happen and cleanup cannot recover the board

---

## 8. Recovery Rules

Use the least invasive recovery that fits the observed state:

- `BOOT_RECEIVING` or `BOOT_VERIFIED`: use `--cleanup-session`
- `BOOT_PENDING_TEST` or candidate awaiting confirmation: use `--cleanup-session`
- clean stable state with maintenance still active: use `--cleanup-session`
- no CAN response at all: move to USB/BOOTSEL or SWD recovery

Do not start a new write session until the controller is confirmed clean by
`--info-only`.

---

## 9. Recommended Order

Run the scenarios in this order:

1. Scenario B
2. Scenario A
3. Scenario C

Why:

- Scenario B is the least risky
- Scenario A validates write-path recovery
- Scenario C is the harshest because it crosses the boot selector boundary

---

## 10. Exit Condition

This campaign was completed on `2026-04-08` when:

- all 3 power-loss scenarios have been executed on real hardware
- all raw logs are saved
- final board state is restored to a clean stable slot
- the result is summarized back into:
  - `software/docs/CAN_FIRMWARE_UPDATE_IMPLEMENTATION_STEPS.md`
  - `software/docs/CAN_FIRMWARE_UPDATE_PROTOCOL_SPEC.md`
  - `software/docs/FIRMWARE_UPDATE_AND_PERSISTENCE_PLAN.md`

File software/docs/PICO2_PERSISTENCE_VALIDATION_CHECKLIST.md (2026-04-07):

# Pico 2 Persistence Validation Checklist

## Scope

This checklist validates the new top-of-flash NVM layout and the legacy-to-new
flash migration path introduced after the persistent-data refactor.

It is intentionally split into two hardware levels:

- **Level A: bare Pico 2 dev board**
  Validates USB flashing, provisioning persistence, and legacy-to-new migration
  of `SystemSettingsData.joint_type`.
- **Level B: full joint-controller hardware**
  Validates the complete persistence set:
  - provisioning / `joint_profile`
  - PID flash data
  - linear equations
  - motor offsets
  - direct encoder offsets

This checklist does **not** apply to an RP2040 Pico. The firmware and flash map
in this repo target Pico 2 / RP2350 only.

---

## Goal

Prove all of the following:

1. The current firmware keeps persistent data outside the application growth path.
2. Reflashing current firmware does not wipe the new NVM region.
3. Boards previously written with the legacy flash layout can migrate forward.
4. Migration is one-way and stable: after the first boot on new firmware, the
   board should behave like a native new-layout board.

---

## Executed Result (2026-04-07)

`Level A` has been executed successfully on real hardware.

- Board type: Pico 2 / RP2350 mounted on a joint-controller board
- Board UID: `8242201C80B670BF`
- Current-firmware reflash stability was confirmed first with the stored profile
  still present after reflashing
- The new top-of-flash NVM region was then cleared explicitly
- A legacy firmware build was flashed and used to store `KNEE_RIGHT` in the
  legacy system-settings slot
- The current firmware was flashed again and the first boot logged:
  - `System settings found only in legacy flash slot - migrating to top-of-flash NVM`
  - `Runtime joint profile loaded from flash: knee_right`
- A second current-firmware reflash preserved `KNEE_RIGHT`, confirming that the
  migrated record survived without needing the legacy slot anymore

Observed identity after migration:

```text
RSP:IDENTITY(2):PROFILE=KNEE_RIGHT:STORED_PROFILE=KNEE_RIGHT:SOURCE=FLASH:UID=8242201C80B670BF:FW=0.1.0
```

Note:
- this same board also contained legacy motor-offset data from an older
  `HIP_ROLL_BENCH_RIGHT` provisioning state
- the current firmware detected and migrated that record as well
- under `KNEE_RIGHT`, the migrated motor-offset record correctly reported a
  joint-type mismatch at runtime, which is expected for this board history

---

## Preconditions

- Use a **Pico 2 / RP2350** board
- Use the repo state that includes:
  - `include/flash_map.h`
  - `scripts/add_flash_nvm_guard.py`
- Build from:
  - [platformio.ini](../firmware/joint_controller/platformio.ini)
- Prefer `pico2_debug` during validation because migration messages are easier to
  observe over USB serial
- Know the USB serial port path, for example:

```bash
ls /dev/cu.usbmodem*
```

Working directory for all firmware commands, from the repo root:

```bash
cd software/firmware/joint_controller
```

---

## Build Commands

Build release:

```bash
~/.platformio/penv/bin/pio run -e pico2
```

Build debug:

```bash
~/.platformio/penv/bin/pio run -e pico2_debug
```

Upload debug to a connected Pico 2:

```bash
~/.platformio/penv/bin/pio run -e pico2_debug -t upload --upload-port /dev/cu.usbmodemXXXX
```

Open serial monitor:

```bash
~/.platformio/penv/bin/pio device monitor -b 115200 -p /dev/cu.usbmodemXXXX
```

---

## Serial Commands Used In This Checklist

Manual USB commands must include the `CMD:` prefix.

Use these exact forms:

```text
CMD:GET_IDENTITY
CMD:SET_JOINT_PROFILE:KNEE_RIGHT
CMD:SET_JOINT_PROFILE:ANKLE_RIGHT
CMD:SET_JOINT_PROFILE:HIP_RIGHT
CMD:SET_JOINT_PROFILE:HIP_ROLL_BENCH_RIGHT
```

Important notes:

- joint profile names are uppercase, for example `KNEE_RIGHT`
- `SET_JOINT_PROFILE` writes flash immediately and reports `REBOOT_REQUIRED=1`
- after writing a profile, perform a real reboot or reflash before checking boot-time load

Relevant implementation points:
- [commands.h](../firmware/joint_controller/include/commands.h)
- [core0.cpp](../firmware/joint_controller/src/core0.cpp)

---

## Level A: Bare Pico 2 Dev Board

### What this level validates

A bare Pico 2 can validate:
- USB flashing works
- provisioning persists across reboot
- provisioning survives reflashing
- legacy `SystemSettingsData` is migrated to the new NVM region

A bare Pico 2 cannot validate:
- motor-side PID behavior
- linear equation save/load over CAN
- motor offsets
- direct encoder offsets on real hardware

### Phase A1: Clean-Board New-Firmware Provisioning Test

1. Build and upload current `pico2_debug`.
2. Open the USB serial monitor.
3. Wait for boot messages.
4. Send:

```text
CMD:GET_IDENTITY
```

Expected:
- a `RSP:IDENTITY(...)` reply
- valid `UID=...`
- board starts unprovisioned on first boot

5. Send:

```text
CMD:SET_JOINT_PROFILE:KNEE_RIGHT
```

Expected:
- `RSP:JOINT_PROFILE_SET(...):NEW_PROFILE=KNEE_RIGHT:REBOOT_REQUIRED=1`

6. Power-cycle or re-upload the same current firmware.
7. Re-open serial monitor.
8. Send:

```text
CMD:GET_IDENTITY
```

Pass condition:
- `STORED_PROFILE=KNEE_RIGHT`
- boot source indicates persisted flash provisioning

### Phase A2: Reflash-Stability Test

1. With the board already provisioned on current firmware, upload current
   `pico2_debug` again.
2. Re-open serial monitor.
3. Send:

```text
CMD:GET_IDENTITY
```

Pass condition:
- the same stored profile is still present after reflashing

### Phase A3: Legacy-to-New Migration Test (Provisioning Only)

This proves forward migration of the legacy persistence layout.

1. Check out the firmware state immediately **before** the top-of-flash NVM change.
2. Build and upload the old firmware to the same Pico 2.
3. Open serial monitor.
4. Send:

```text
CMD:SET_JOINT_PROFILE:KNEE_RIGHT
```

5. Reboot once to confirm the old firmware sees the stored profile.
6. Check out the **current** firmware again.
7. Build and upload current `pico2_debug`.
8. Open serial monitor and watch boot logs carefully.

Expected on first boot after migration:
- the board loads the profile from the **legacy** system-settings slot
- firmware logs a migration warning similar to:
  - system settings found only in legacy flash slot
  - migrating to top-of-flash NVM

9. Reboot or reflash current firmware one more time.
10. Query again:

```text
CMD:GET_IDENTITY
```

Pass condition:
- stored profile is still present
- the second current-firmware boot should no longer require legacy-only recovery

---

## Level B: Full Joint-Controller Hardware

### What this level adds

A full controller board with MCP2515s, encoders, and bench hardware is required to
validate persistence for:

- PID flash records
- linear equations
- motor offsets
- direct encoder offsets

### Recommended Host Surface

Use the existing host control paths already wired in the repo:

- PID save/load via host UI or host routes
- linear-equation save/load via CAN
- offset checks via host command path
- encoder-offset query via CAN

Relevant implementation points:
- [routes.py](../host/routes.py)
- [serial_handler.py](../host/serial_handler.py)
- [can_manager.py](../host/can_manager.py)

### Phase B1: Old-Firmware Save

Using the pre-migration firmware on a real controller:

1. Provision the board to the intended profile.
2. Save PID to flash.
3. Save linear equations to flash.
4. Run the calibration path that saves motor offsets.
5. Save direct encoder offsets if that bench path is available.
6. Record:
   - profile
   - PID values
   - equation presence
   - offset validation state
   - encoder offset query result

### Phase B2: Migration Boot

1. Flash the **current** firmware to the same controller.
2. Observe first boot.
3. Expect migration logs for whichever legacy records exist:
   - PID
   - linear equations
   - system settings
   - motor offsets
   - encoder offsets

Pass condition:
- each legacy record that existed is loaded successfully
- the controller stays usable after first boot on the new firmware

### Phase B3: Post-Migration Reflash Stability

1. Flash the **current** firmware again.
2. Use the host UI / CAN / serial service path to verify:
   - profile still present
   - `LOAD_PID` succeeds
   - `LOAD_LINEAR_EQUATIONS` succeeds
   - `CHECK_OFFSETS` behaves as expected
   - encoder-offset query returns the same saved values

Pass condition:
- data survives a second current-firmware flash without needing the legacy layout

---

## Evidence To Save

For any successful run, save:

- firmware environment used: `pico2` or `pico2_debug`
- firmware repo commit / worktree state
- serial log or host log
- the exact board UID
- the stored profile before and after reflashing
- whether legacy migration was observed
- whether second-flash persistence still passed

For Level B also save:

- PID save/load evidence
- linear-equation save/load evidence
- offset-check evidence
- encoder-offset query result

---

## Minimal Acceptance

### Minimum acceptable result on a bare Pico 2

- current firmware provisions successfully
- profile survives reboot
- profile survives reflashing
- legacy `SystemSettingsData` migrates forward to the new layout

### Minimum acceptable result on a full controller

- all of the above
- PID survives migration
- linear equations survive migration
- motor offsets survive migration
- direct encoder offsets survive migration

---

## Failure Handling

If a step fails:

1. keep the serial or host log
2. note whether the failure happened on:
   - old firmware save
   - first current-firmware boot
   - second current-firmware flash
   - specific record type (`profile`, `PID`, `linear_eq`, `motor_offsets`, `encoder_offsets`)
3. do not erase the board immediately if the goal is migration diagnosis

The first board to run this checklist should be treated as an experiment board, not
production bench hardware.

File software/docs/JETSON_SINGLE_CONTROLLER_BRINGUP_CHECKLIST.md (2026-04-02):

# Jetson Single-Controller Bring-Up Checklist

## Scope

This checklist is the first real hardware validation step for the CAN-first diagnostics
plane.

Use it before attempting any 2-controller or 6-controller integrated bring-up.

Primary target example:

- `KNEE_RIGHT`

Equivalent single-controller variants are acceptable if the bench hardware differs, as
long as the same evidence is collected.

## Goal

Prove that one controller can be brought up, observed, faulted, and diagnosed from CAN
only, without relying on USB serial as the primary debugging path.

## Preconditions

- Firmware on the controller matches the current diagnostics baseline
- Jetson host CAN path is wired and reachable
- Mechanical setup is safe for motion at home / hold / small nudge
- Emergency stop path is functional
- The operator can capture:
  - Jetson session log
  - JSONL diagnostic history
  - one TUI screenshot

## Launch Command

From `software/host/jetson_controller/`:

```bash
./run_knee_right_can_only.sh
```

If the bench uses another single joint:

```bash
./run.sh --no-serial --preflight-auto --joint <joint_name>
```

## Operator Controls Used During This Test

- `D` — discover
- `S` — startup
- `H` or `0` — move to home target
- `+` / `-` — nudge selected DOF
- `E` — emergency stop
- `R` — request fault snapshot for selected joint
- `Q` — quit

## Checklist
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

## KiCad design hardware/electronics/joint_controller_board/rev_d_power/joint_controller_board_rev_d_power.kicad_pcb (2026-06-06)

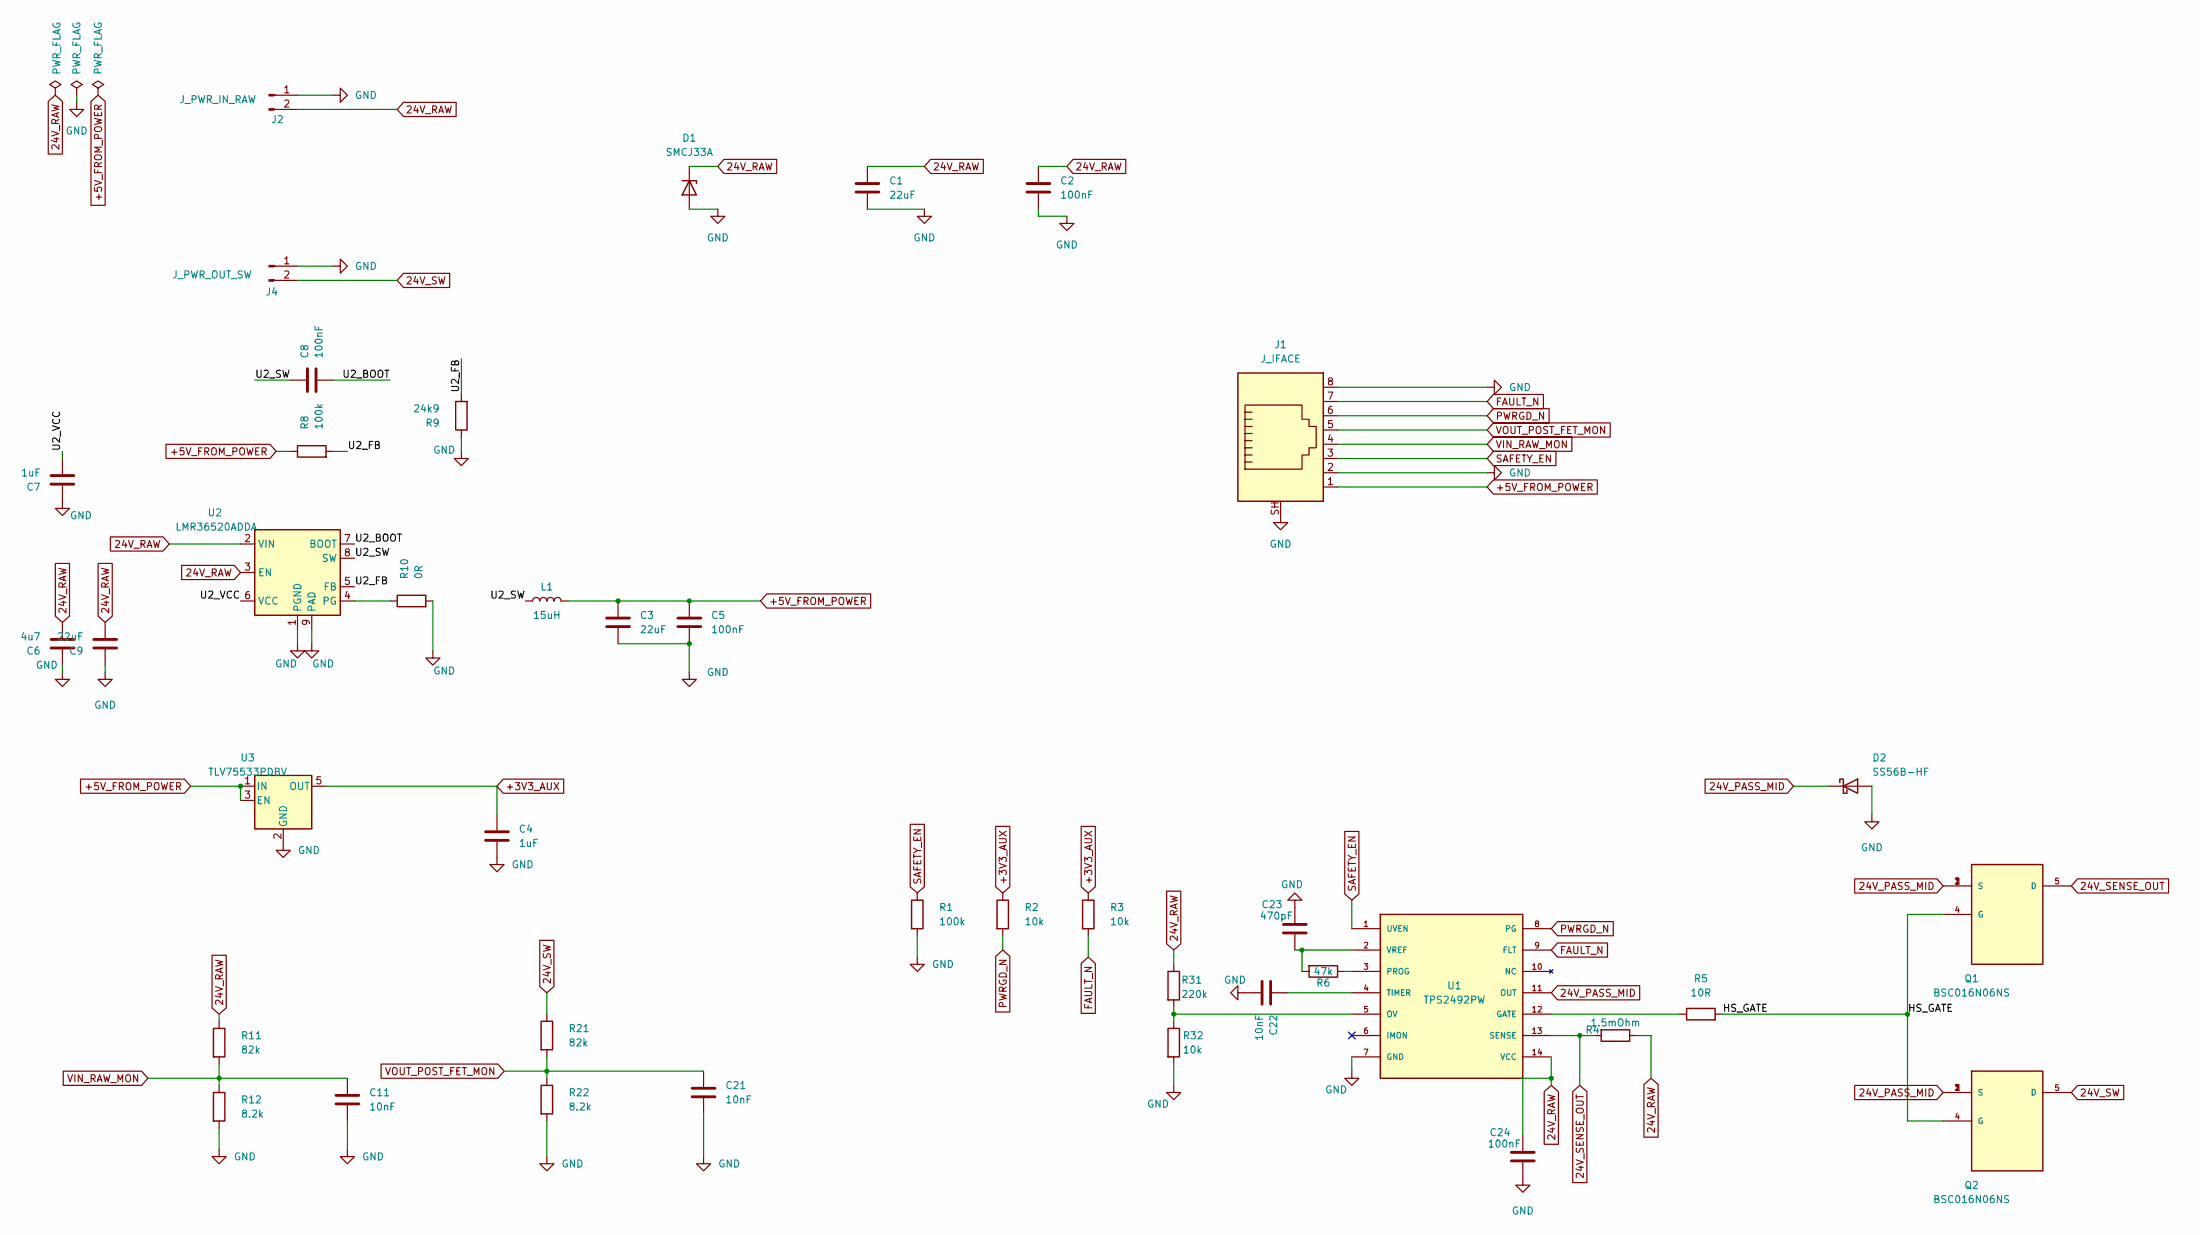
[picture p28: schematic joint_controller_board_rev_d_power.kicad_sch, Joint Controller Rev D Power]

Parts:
C1, C9: 22uF; C_1210_3225Metric
C2, C5, C8, C24: 100nF; C_0805_2012Metric
C3: 22uF; C_0805_2012Metric
C4, C7: 1uF; C_0805_2012Metric
C6: 4u7; C_1210_3225Metric
C11, C21, C22: 10nF; C_0805_2012Metric
C23: 470pF; C_0805_2012Metric
D1: SMCJ33A; D_SMC; MPN SMCJ33A
D2: SS56B-HF; D_SMB; MPN SS56B-HF
J1: J_IFACE; RJ45_Amphenol_RJHSE5380; MPN RJHSE-5380
J2: J_PWR_IN_RAW; AMASS_XT60PW-F_1x02_P7.20mm_Horizontal; MPN XT60PW-F
J4: J_PWR_OUT_SW; AMASS_XT60PW-M_1x02_P7.20mm_Horizontal; MPN XT60PW-M
L1: 15uH; L_Bourns_SRP5030T; MPN SRP5030T-150M
Q1, Q2: BSC016N06NS; TDSON-8-1; MPN BSC016N06NSATMA1
R1, R8: 100k; R_0805_2012Metric
R2, R3, R32: 10k; R_0805_2012Metric
R4: 1.5mOhm; R_Shunt_Vishay_WSR2_WSR3_KelvinConnection; MPN WSR31L500FEA
R5: 10R; R_0805_2012Metric
R6: 47k; R_0805_2012Metric
R9: 24k9; R_0805_2012Metric
R10: 0R; R_0805_2012Metric
R11, R21: 82k; R_0805_2012Metric
R12, R22: 8.2k; R_0805_2012Metric
R31: 220k; R_0805_2012Metric
U1: TPS2492PW; TSSOP-14_4.4x5mm_P0.65mm; MPN TPS2492PW
U2: LMR36520ADDA; Texas_HTSOP-8-1EP_3.9x4.9mm_P1.27mm_EP2.95x4.9mm_Mask2.4x3.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; MPN LMR36520ADDAR
U3: TLV75533PDBV; SOT-23-5; MPN TLV75533PDBVR

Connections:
24V_PASS_MID: D2.1 (K), Q1.1 (S), Q1.2 (S), Q1.3 (S), Q2.1 (S), Q2.2 (S), Q2.3 (S), U1.11 (OUT)
24V_RAW: C1.1, C2.1, C6.2, C9.2, C24.2, D1.1 (K), J2.2, R4.1, R11.1, R31.1, U1.14 (VCC), U2.2 (VIN), U2.3 (EN)
24V_SENSE_OUT: Q1.5 (D), R4.2, U1.13 (SENSE)
24V_SW: J4.2, Q2.5 (D), R21.1
+3V3_AUX: C4.1, R2.1, R3.1, U3.5 (OUT)
+5V_FROM_POWER: C3.1, C5.1, J1.1, L1.2, R8.1, U3.1 (IN), U3.3 (EN)
/HS_GATE: Q1.4 (G), Q2.4 (G), R5.2
/U2_BOOT: C8.2, U2.7 (BOOT)
/U2_FB: R8.2, R9.2, U2.5 (FB)
/U2_SW: C8.1, L1.1, U2.8 (SW)
/U2_VCC: C7.2, U2.6 (VCC)
FAULT_N: J1.7, R3.2, U1.9 (FLT)
GND: C1.2, C2.2, C3.2, C4.2, C5.2, C6.1, C7.1, C9.1, C11.2, C21.2, C22.2, C23.2, C24.1, D1.2 (A), D2.2 (A), J1.2, J1.8, J1.SH, J2.1, J4.1, R1.2, R9.1, R10.2, R12.2, R22.2, R32.2, U1.7 (GND), U2.1 (PGND), U2.9 (PAD), U3.2 (GND)
unnamed: R5.1, U1.12 (GATE)
unnamed: R31.2, R32.1, U1.5 (OV)
unnamed: R6.1, U1.3 (PROG)
unnamed: C22.1, U1.4 (TIMER)
unnamed: C23.1, R6.2, U1.2 (VREF)
unnamed: R10.1, U2.4 (PG)
PWRGD_N: J1.6, R2.2, U1.8 (PG)
SAFETY_EN: J1.3, R1.1, U1.1 (UVEN)
VIN_RAW_MON: C11.1, J1.4, R11.2, R12.1
VOUT_POST_FET_MON: C21.1, J1.5, R21.2, R22.1

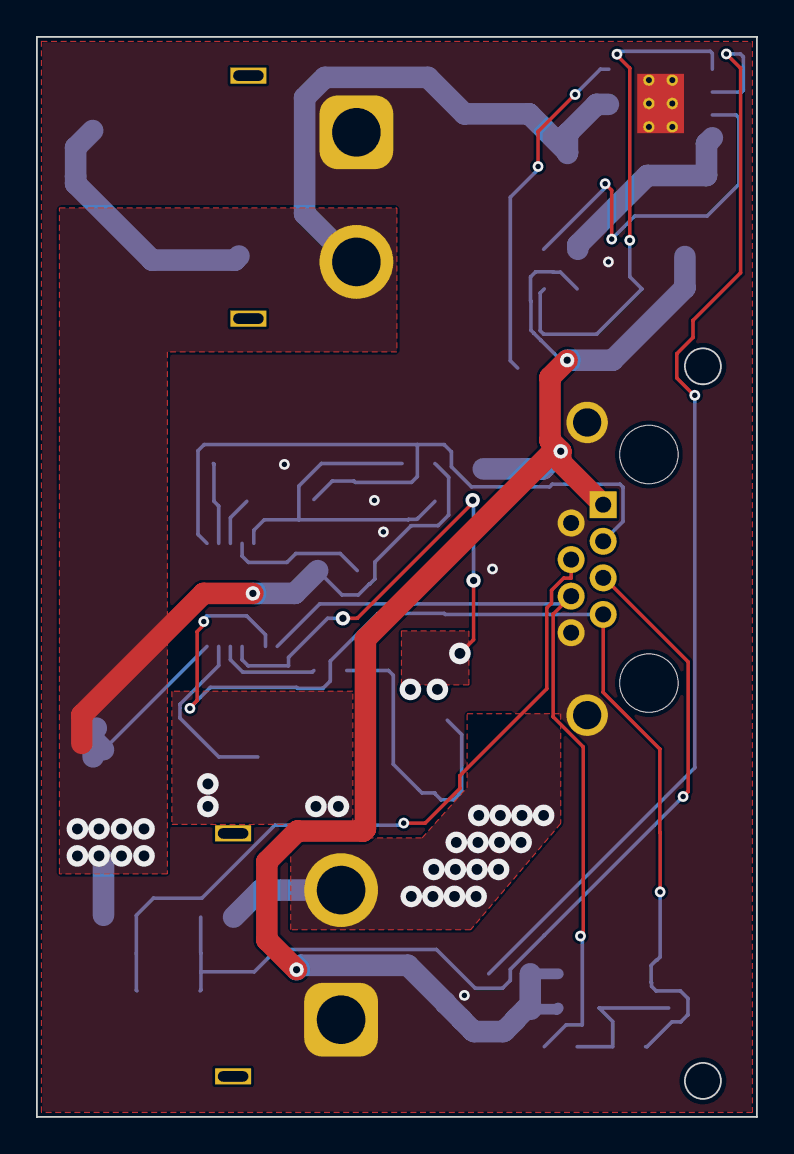
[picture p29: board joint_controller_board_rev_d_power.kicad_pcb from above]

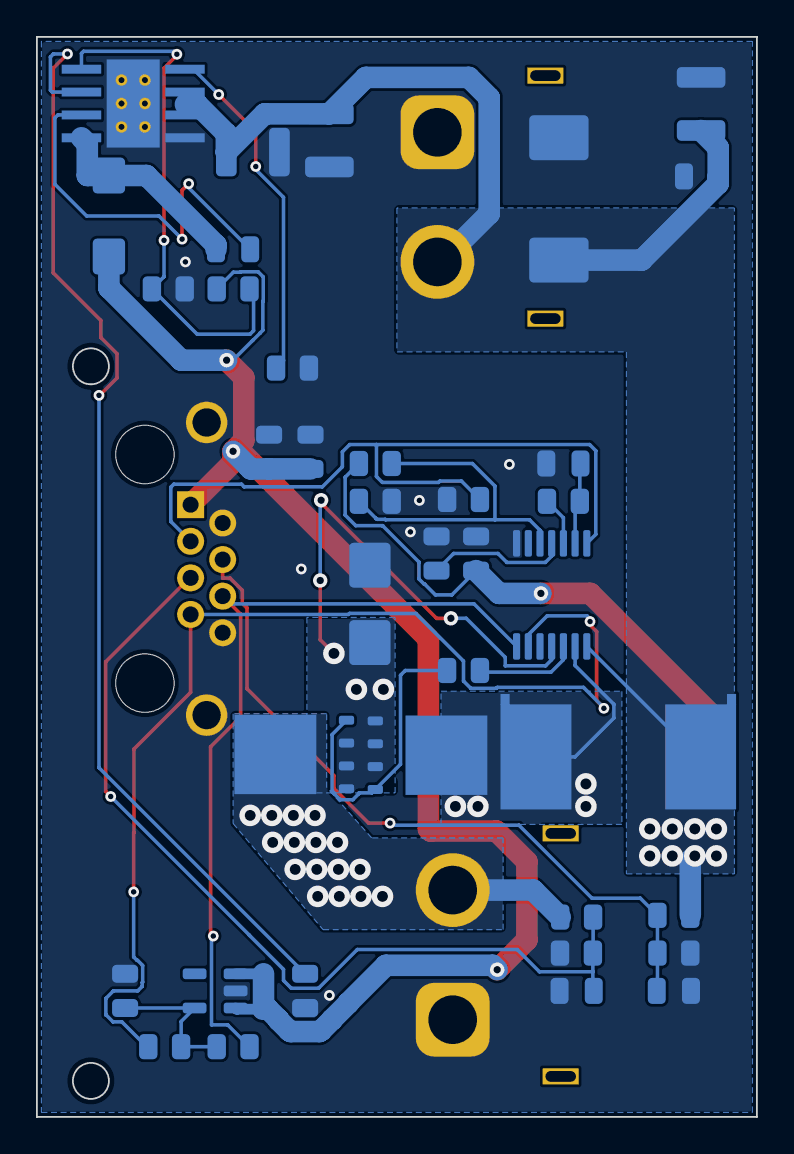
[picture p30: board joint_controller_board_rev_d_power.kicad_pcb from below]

Board: 2 copper layers, 40.0 x 60.0 mm, 40 parts (37 on the bottom side), 23 nets.

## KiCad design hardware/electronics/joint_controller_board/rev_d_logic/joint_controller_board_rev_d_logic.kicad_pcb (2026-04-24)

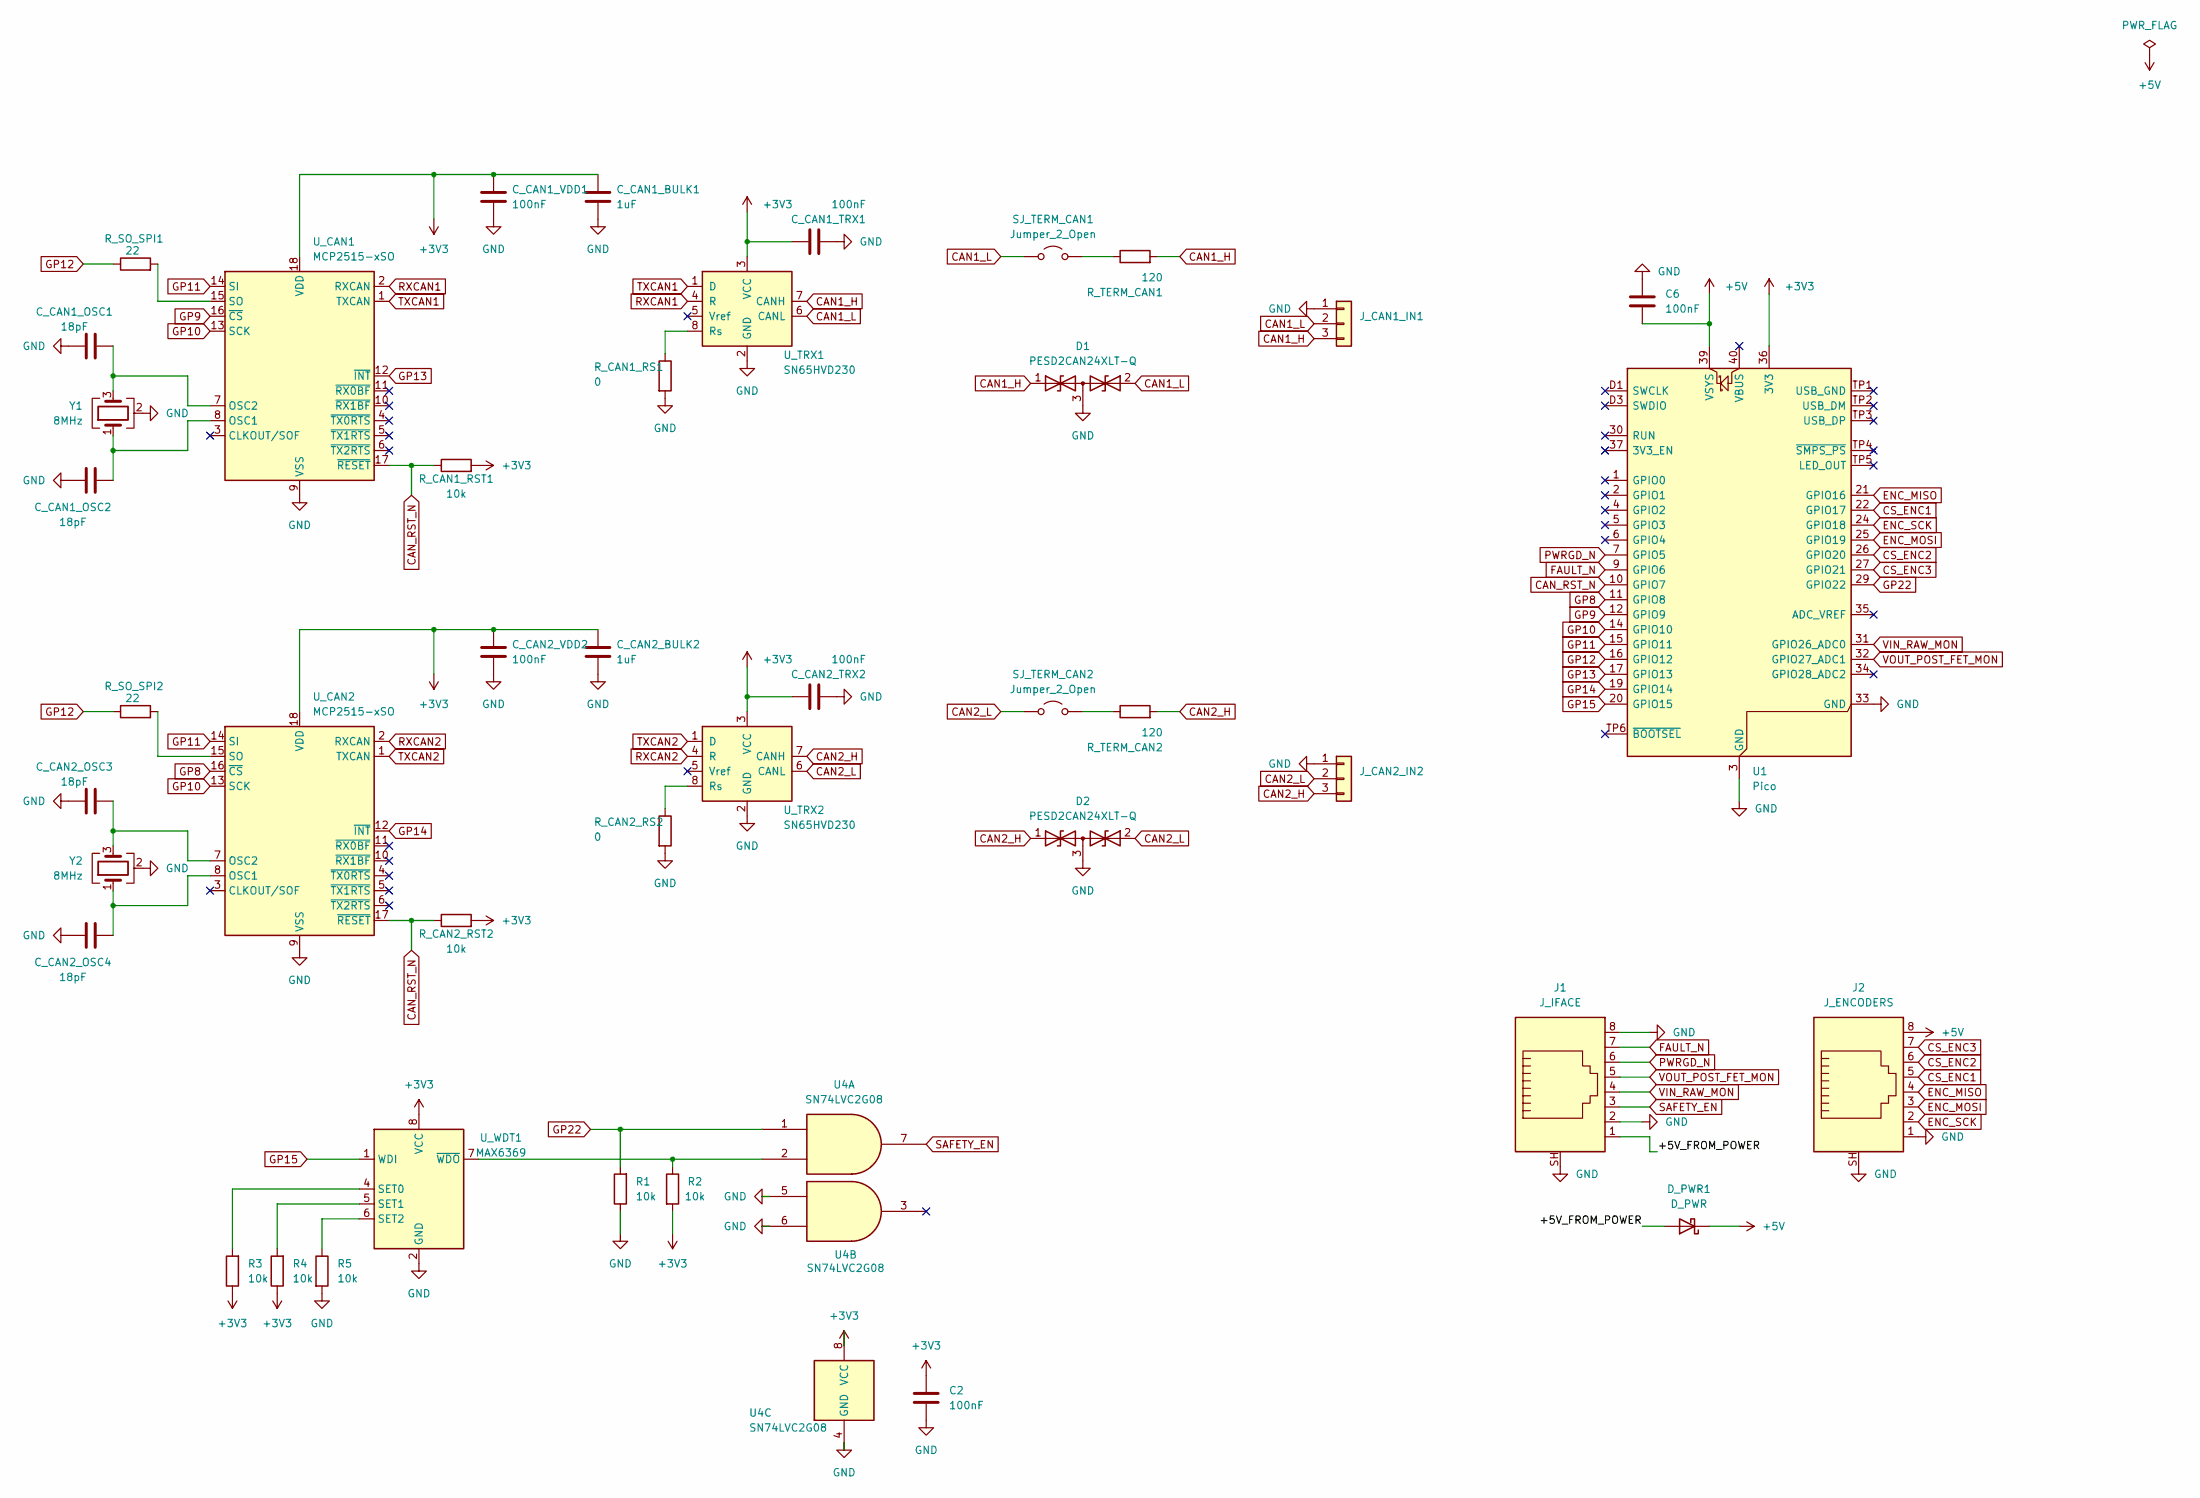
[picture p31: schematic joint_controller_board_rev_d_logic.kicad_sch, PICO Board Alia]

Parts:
C2, C6: 100nF; C_0805_2012Metric
C_CAN1_BULK1, C_CAN2_BULK2: 1uF; C_0805_2012Metric
C_CAN1_OSC1, C_CAN1_OSC2, C_CAN2_OSC3, C_CAN2_OSC4: 18pF; C_0805_2012Metric
C_CAN1_TRX1, C_CAN1_VDD1, C_CAN2_TRX2, C_CAN2_VDD2: 100nF; C_0805_2012Metric
D1, D2: PESD2CAN24XLT-Q; SOT-23
D_PWR1: D_PWR; D_SMA
J1: J_IFACE; RJ45_Amphenol_RJHSE5380
J2: J_ENCODERS; RJ45_Amphenol_RJHSE5380
J_CAN1_IN1, J_CAN2_IN2: TerminalBlock_Phoenix_MPT-0,5-3-2.54_1x03_P2.54mm_Horizontal
R1, R2, R3, R4, R5: 10k; R_0805_2012Metric
R_CAN1_RS1, R_CAN2_RS2: 0; R_0805_2012Metric
R_CAN1_RST1, R_CAN2_RST2: 10k; R_0805_2012Metric
R_SO_SPI1, R_SO_SPI2: 22; R_0805_2012Metric
R_TERM_CAN1, R_TERM_CAN2: 120; R_0805_2012Metric
SJ_TERM_CAN1, SJ_TERM_CAN2: Jumper_2_Open; SolderJumper-2_P1.3mm_Open_TrianglePad1.0x1.5mm
U1: Pico; RaspberryPi_Pico_Common_THT
U4: SN74LVC2G08; VSSOP-8_2.4x2.1mm_P0.5mm
U_CAN1, U_CAN2: MCP2515-xSO; SOIC-18W_7.5x11.6mm_P1.27mm
U_TRX1, U_TRX2: SN65HVD230; SOIC-8_3.9x4.9mm_P1.27mm
U_WDT1: MAX6369; SOT-23-8
Y1, Y2: 8MHz; Crystal_SMD_3225-4Pin_3.2x2.5mm

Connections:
+3V3: C2.1, C_CAN1_BULK1.1, C_CAN1_TRX1.1, C_CAN1_VDD1.1, C_CAN2_BULK2.1, C_CAN2_TRX2.1, C_CAN2_VDD2.1, R2.2, R3.1, R4.1, R_CAN1_RST1.2, R_CAN2_RST2.2, U1.36 (3V3), U4.8 (VCC), U_CAN1.18 (VDD), U_CAN2.18 (VDD), U_TRX1.3 (VCC), U_TRX2.3 (VCC), U_WDT1.8 (VCC)
+5V: C6.2, D_PWR1.1 (K), J2.8, U1.39 (VSYS)
/+5V_FROM_POWER: D_PWR1.2 (A), J1.1
CAN1_H: D1.1 (A1), J_CAN1_IN1.3, R_TERM_CAN1.2, U_TRX1.7 (CANH)
CAN1_L: D1.2 (A2), J_CAN1_IN1.2, SJ_TERM_CAN1.1 (A), U_TRX1.6 (CANL)
CAN2_H: D2.1 (A1), J_CAN2_IN2.3, R_TERM_CAN2.2, U_TRX2.7 (CANH)
CAN2_L: D2.2 (A2), J_CAN2_IN2.2, SJ_TERM_CAN2.1 (A), U_TRX2.6 (CANL)
CAN_RST_N: R_CAN1_RST1.1, R_CAN2_RST2.1, U1.10 (GPIO7), U_CAN1.17 (~RESET), U_CAN2.17 (~RESET)
CS_ENC1: J2.5, U1.22 (GPIO17)
CS_ENC2: J2.6, U1.26 (GPIO20)
CS_ENC3: J2.7, U1.27 (GPIO21)
ENC_MISO: J2.4, U1.21 (GPIO16)
ENC_MOSI: J2.3, U1.25 (GPIO19)
ENC_SCK: J2.2, U1.24 (GPIO18)
FAULT_N: J1.7, U1.9 (GPIO6)
GND: C2.2, C6.1, C_CAN1_BULK1.2, C_CAN1_OSC1.1, C_CAN1_OSC2.1, C_CAN1_TRX1.2, C_CAN1_VDD1.2, C_CAN2_BULK2.2, C_CAN2_OSC3.1, C_CAN2_OSC4.1, C_CAN2_TRX2.2, C_CAN2_VDD2.2, D1.3 (common), D2.3 (common), J1.2, J1.8, J1.SH, J2.1, J2.SH, J_CAN1_IN1.1, J_CAN2_IN2.1, R1.1, R5.2, R_CAN1_RS1.2, R_CAN2_RS2.2, U1.3 (GND), U1.8 (GND), U1.13 (GND), U1.18 (GND), U1.23 (GND), U1.28 (GND), U1.33 (GND), U1.38 (GND), U1.D2 (GND), U4.4 (GND), U4.5, U4.6, U_CAN1.9 (VSS), U_CAN2.9 (VSS), U_TRX1.2 (GND), U_TRX2.2 (GND), U_WDT1.2 (GND), Y1.2 (G), Y1.4 (G), Y2.2 (G), Y2.4 (G)
GP8: U1.11 (GPIO8), U_CAN2.16 (~CS)
GP9: U1.12 (GPIO9), U_CAN1.16 (~CS)
GP10: U1.14 (GPIO10), U_CAN1.13 (SCK), U_CAN2.13 (SCK)
GP11: U1.15 (GPIO11), U_CAN1.14 (SI), U_CAN2.14 (SI)
GP12: R_SO_SPI1.1, R_SO_SPI2.1, U1.16 (GPIO12)
GP13: U1.17 (GPIO13), U_CAN1.12 (~INT)
GP14: U1.19 (GPIO14), U_CAN2.12 (~INT)
GP15: U1.20 (GPIO15), U_WDT1.1 (WDI)
GP22: R1.2, U1.29 (GPIO22), U4.1
unnamed: R_TERM_CAN1.1, SJ_TERM_CAN1.2 (B)
unnamed: R_TERM_CAN2.1, SJ_TERM_CAN2.2 (B)
unnamed: C_CAN1_OSC2.2, U_CAN1.8 (OSC1), Y1.1
unnamed: C_CAN1_OSC1.2, U_CAN1.7 (OSC2), Y1.3
unnamed: R_SO_SPI1.2, U_CAN1.15 (SO)
unnamed: C_CAN2_OSC4.2, U_CAN2.8 (OSC1), Y2.1
unnamed: C_CAN2_OSC3.2, U_CAN2.7 (OSC2), Y2.3
unnamed: R_SO_SPI2.2, U_CAN2.15 (SO)
unnamed: R_CAN1_RS1.1, U_TRX1.8 (Rs)
unnamed: R_CAN2_RS2.1, U_TRX2.8 (Rs)
unnamed: R3.2, U_WDT1.4 (SET0)
unnamed: R4.2, U_WDT1.5 (SET1)
unnamed: R5.1, U_WDT1.6 (SET2)
unnamed: R2.1, U4.2, U_WDT1.7 (~WDO)
PWRGD_N: J1.6, U1.7 (GPIO5)
RXCAN1: U_CAN1.2 (RXCAN), U_TRX1.4 (R)
RXCAN2: U_CAN2.2 (RXCAN), U_TRX2.4 (R)
SAFETY_EN: J1.3, U4.7
TXCAN1: U_CAN1.1 (TXCAN), U_TRX1.1 (D)
TXCAN2: U_CAN2.1 (TXCAN), U_TRX2.1 (D)
VIN_RAW_MON: J1.4, U1.31 (GPIO26_ADC0)
VOUT_POST_FET_MON: J1.5, U1.32 (GPIO27_ADC1)

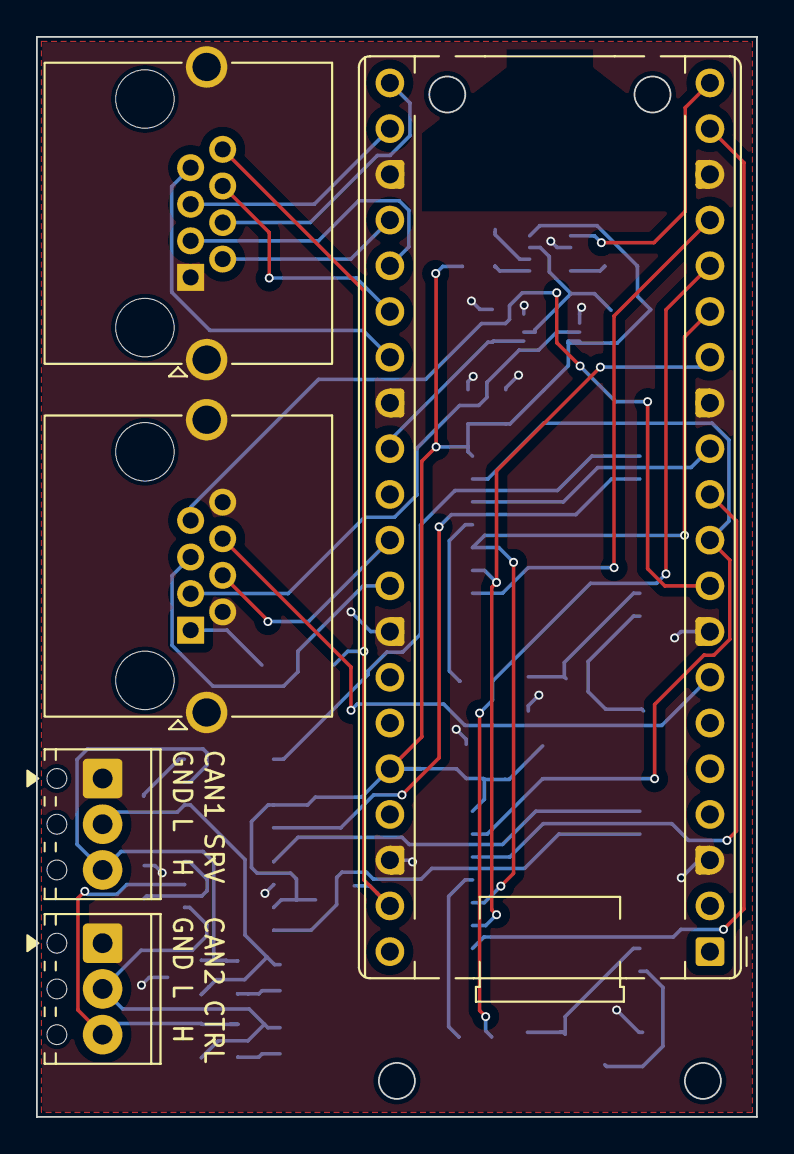
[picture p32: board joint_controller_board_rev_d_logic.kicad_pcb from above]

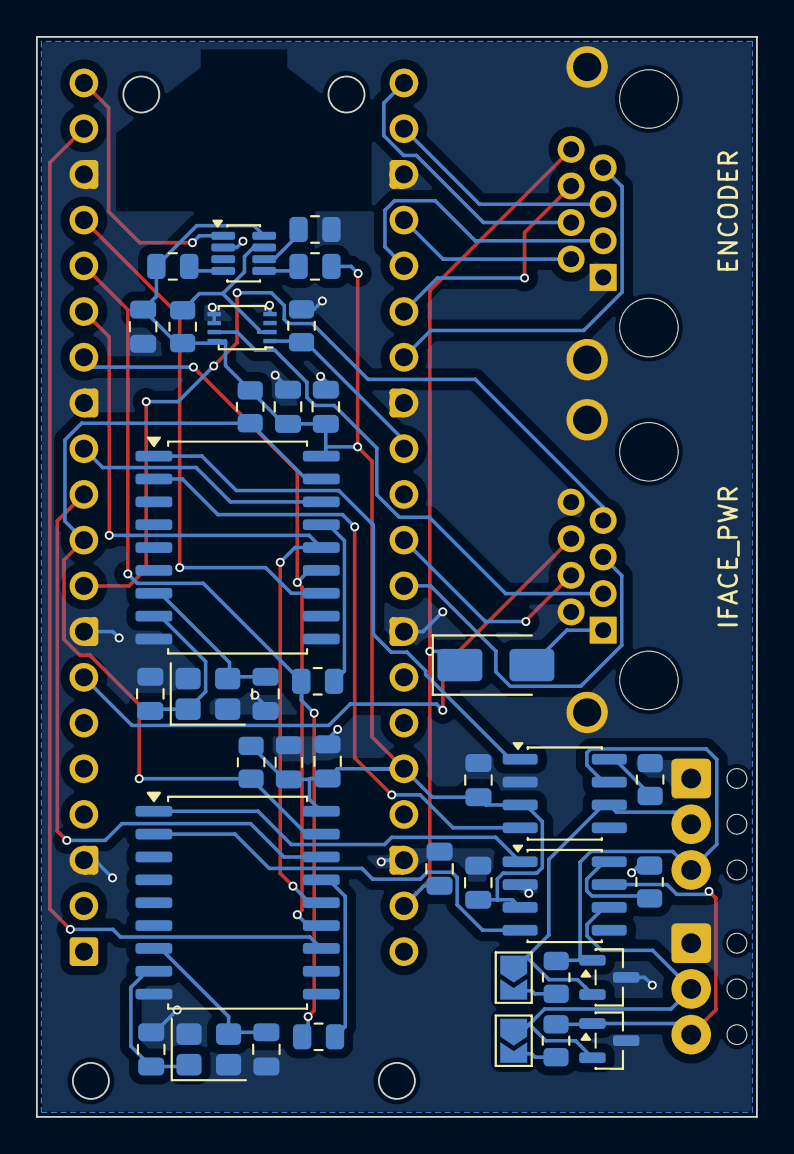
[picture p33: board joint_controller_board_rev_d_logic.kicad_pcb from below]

Board: 2 copper layers, 40.0 x 60.0 mm, 43 parts (38 on the bottom side), 47 nets.

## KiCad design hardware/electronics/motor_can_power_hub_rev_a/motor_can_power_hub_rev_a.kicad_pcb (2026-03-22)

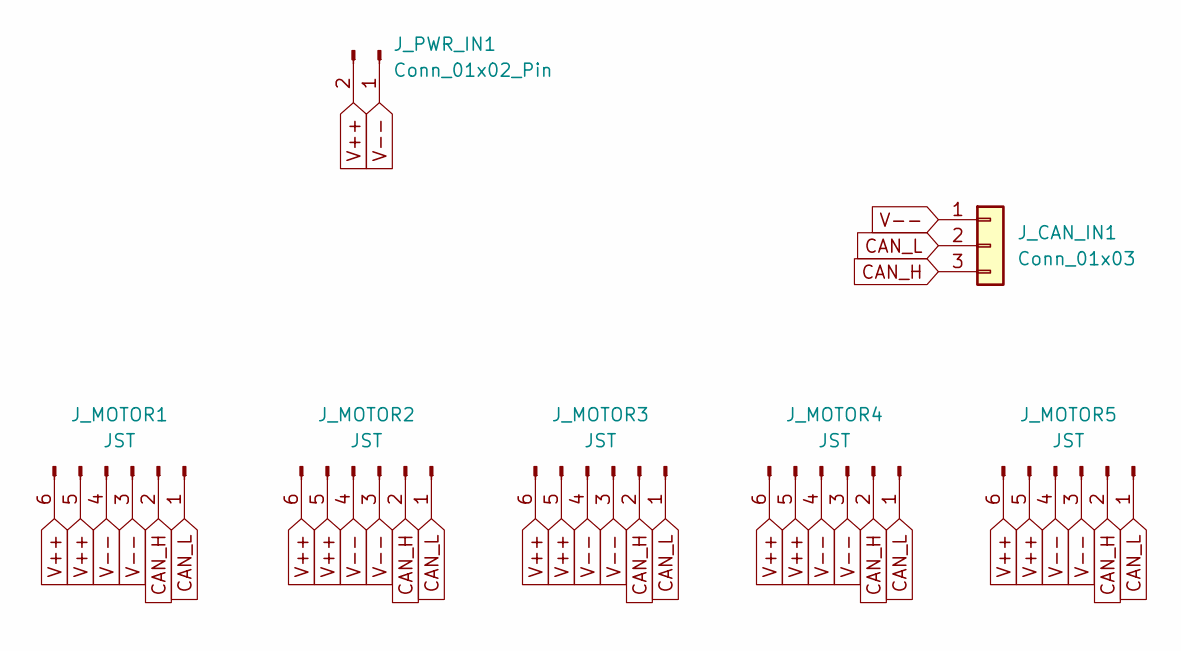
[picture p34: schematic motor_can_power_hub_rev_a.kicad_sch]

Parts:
J_CAN_IN1: Conn_01x03; TerminalBlock_Phoenix_MPT-0,5-3-2.54_1x03_P2.54mm_Horizontal
J_MOTOR1, J_MOTOR2, J_MOTOR3, J_MOTOR4, J_MOTOR5: JST; JST_ZH_B6B-ZR_1x06_P1.50mm_Vertical
J_PWR_IN1: Conn_01x02_Pin; AMASS_XT60PW-M_1x02_P7.20mm_Horizontal

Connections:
CAN_H: J_CAN_IN1.3, J_MOTOR1.2, J_MOTOR2.2, J_MOTOR3.2, J_MOTOR4.2, J_MOTOR5.2
CAN_L: J_CAN_IN1.2, J_MOTOR1.1, J_MOTOR2.1, J_MOTOR3.1, J_MOTOR4.1, J_MOTOR5.1
V++: J_MOTOR1.5, J_MOTOR1.6, J_MOTOR2.5, J_MOTOR2.6, J_MOTOR3.5, J_MOTOR3.6, J_MOTOR4.5, J_MOTOR4.6, J_MOTOR5.5, J_MOTOR5.6, J_PWR_IN1.2
V--: J_CAN_IN1.1, J_MOTOR1.3, J_MOTOR1.4, J_MOTOR2.3, J_MOTOR2.4, J_MOTOR3.3, J_MOTOR3.4, J_MOTOR4.3, J_MOTOR4.4, J_MOTOR5.3, J_MOTOR5.4, J_PWR_IN1.1

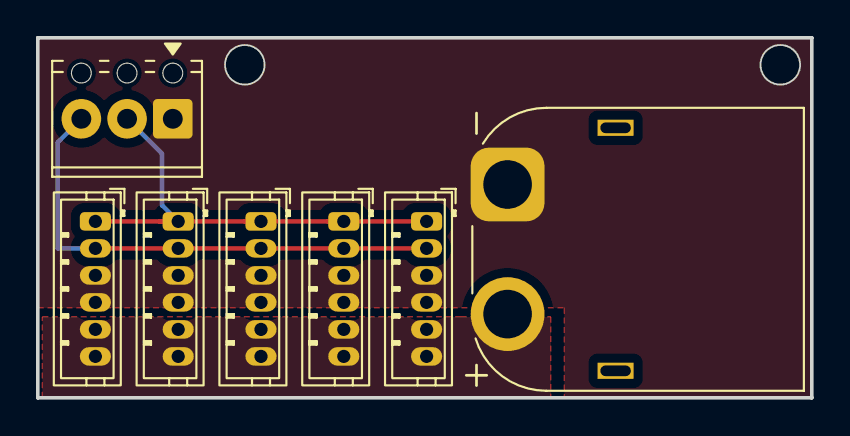
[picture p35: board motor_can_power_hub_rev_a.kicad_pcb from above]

Board: 2 copper layers, 43.0 x 20.0 mm, 7 parts (0 on the bottom side), 4 nets.

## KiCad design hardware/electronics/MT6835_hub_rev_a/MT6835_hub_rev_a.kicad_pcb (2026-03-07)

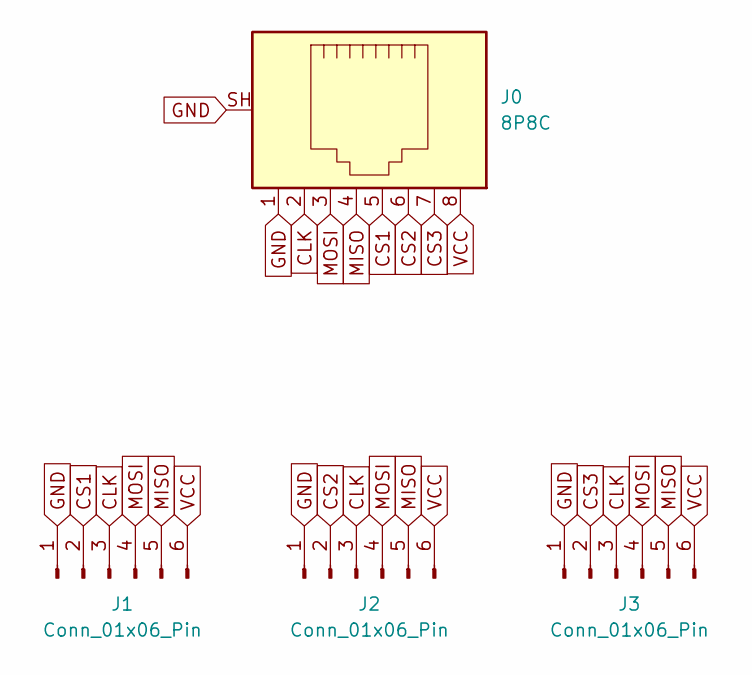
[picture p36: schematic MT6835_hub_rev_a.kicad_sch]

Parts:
J0: 8P8C; RJ45_Amphenol_RJHSE5380
J1, J2, J3: Conn_01x06_Pin; Molex_PicoBlade_53398-0671_1x06-1MP_P1.25mm_Vertical

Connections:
CLK: J0.2, J1.3, J2.3, J3.3
CS1: J0.5, J1.2
CS2: J0.6, J2.2
CS3: J0.7, J3.2
GND: J0.1, J0.SH, J1.1, J2.1, J3.1
MISO: J0.4, J1.5, J2.5, J3.5
MOSI: J0.3, J1.4, J2.4, J3.4
VCC: J0.8, J1.6, J2.6, J3.6

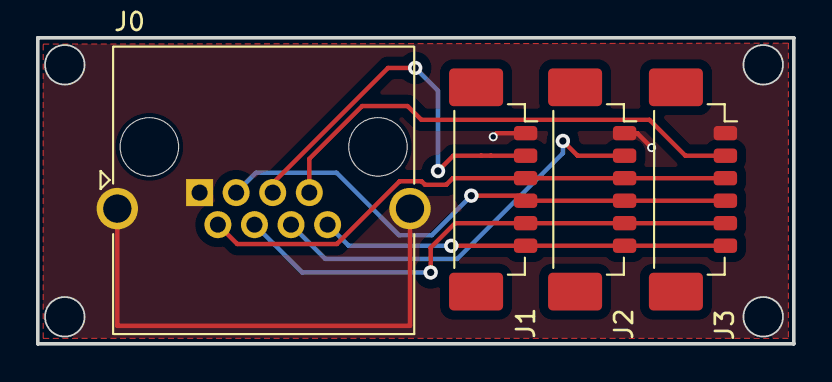
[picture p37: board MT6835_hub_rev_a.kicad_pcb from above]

Board: 2 copper layers, 42.0 x 17.0 mm, 4 parts (0 on the bottom side), 8 nets.

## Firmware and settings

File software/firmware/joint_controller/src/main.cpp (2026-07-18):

/**
 * @file main.cpp
 * @brief Main entry point for joint controller firmware - System initialization only
 *
 * This file contains:
 * - Global variable definitions (shared across cores)
 * - setup() function for system initialization
 *
 * Core execution loops have been separated for better modularity:
 * - Core0 loop (serial communication) is implemented in core0.cpp
 * - Core1 loop (hardware operations) is implemented in core1.cpp
 *
 * @see main_common.h for shared declarations
 * @see core0.cpp for serial communication and command dispatch
 * @see core1.cpp for movement execution and hardware access
 */

#include "main_common.h"
#include "BootUpdateBreadcrumb.h"
#include "FirmwareUpdateMetadata.h"
#include "RuntimeProvisioning.h"

// --- Overclock support (env pico2_debug_rev_d_oc200: board_build.f_cpu > 150MHz) -----------
// Compiled out entirely at the default 150MHz -> all non-OC envs stay bit-identical.
#if defined(PICO_RP2350) && (F_CPU > 150000000)
#include <hardware/vreg.h>
#include <hardware/clocks.h>
// arduino-pico raises the core regulator for overclocks ONLY on RP2040 (framework main.cpp:
// the vreg bump sits inside #if defined(PICO_RP2040)); on RP2350 set_sys_clock_khz would run
// at the default 1.10V. Raise to 1.15V BEFORE the framework's clock raise:
// __attribute__((constructor)) runs in runtime_init, ahead of the framework's overclock code,
// while the chip still runs the boot clock. ~1ms settle mirrors the framework's own RP2040
// pattern (SYS_CLK_VREG_VOLTAGE_AUTO_ADJUST_DELAY_US).
static void __attribute__((constructor)) _oc_raise_vreg(void) {
  vreg_set_voltage(VREG_VOLTAGE_1_15);
  busy_wait_us(1000);
}
#endif

#ifndef MOTOR_CAN_MCP_BITRATE
#define MOTOR_CAN_MCP_BITRATE CAN_1000KBPS
#endif

#ifndef HOST_CAN_MCP_BITRATE
#define HOST_CAN_MCP_BITRATE CAN_500KBPS
#endif

#ifndef MOTOR_CAN_BITRATE_KBPS
#define MOTOR_CAN_BITRATE_KBPS 1000
#endif

#ifndef HOST_CAN_BITRATE_KBPS
#define HOST_CAN_BITRATE_KBPS 500
#endif

extern "C" uint8_t __flash_binary_start;
extern "C" uint8_t __flash_binary_end;

//----------------------------------------------------------------------------
// RUNTIME JOINT CONFIGURATION
//----------------------------------------------------------------------------
#define ACTIVE_JOINT getRuntimeJointId()
#define ACTIVE_JOINT_CONFIG getRuntimeJointConfig()
//----------------------------------------------------------------------------

#pragma region Variables

// init program flag
bool init_prg = true;
// === CROSS-CORE FLAGS (volatile required — written by one core, read by the other) ===
// On ARM Cortex-M33, aligned ≤32-bit reads/writes are naturally atomic.
// volatile prevents compiler from caching values across loop iterations.
volatile bool flash_operation_in_progress = false;  // Core0 writes, Core1 reads
volatile bool core1_flash_acknowledged = false;     // Core1 writes, Core0 reads
volatile bool core1_runtime_started = false;        // Core1 writes once loop is alive
volatile bool movement_in_progress = false;         // Core1 writes, Core0 reads
volatile bool suspend_host_can_polling = false;     // Core0 writes, Core1 reads
// System settings (loaded from flash at boot)
SystemSettingsData system_settings = {};
bool system_settings_loaded = false;
// Control loop timing (configurable via CAN)
volatile uint16_t inner_loop_period_us = 4000;  // 4000µs = 250Hz (default) — 500Hz overran the
                                                // setTorque budget on multi-motor joints (loop overrun);
                                                // 250Hz runs clean. Still runtime-settable via CAN 0x006.
volatile uint8_t outer_loop_divisor = 1;        // 250Hz/1 = 250Hz (default, same as inner)
volatile uint32_t wp_watchdog_interval = 250;   // S2 sub92 0x92 watchdog interval in cycles (rate-scaled):
                                                // 1e6/4000µs = 250 @250Hz default (~1.0s wall). Recomputed on
                                                // boot (setup) + the 0x006 handler via deriveWpWatchdogInterval().
volatile uint16_t torque_ramp_time_ms = 100;    // Time for 0→max torque (default: 100ms, 0=disabled)
volatile uint16_t encoder_error_threshold_ms = 30;   // Encoder error threshold (default: 30ms — fast e-stop; torque is also cut per-DOF on invalid encoder)
// CAN error detection: time-window based (more robust to EMI glitches)
volatile uint16_t can_error_window_ms = 50;      // 50ms window (default)
volatile uint8_t can_error_threshold = 5;         // 5 errors in window = emergency stop
volatile float can_motor_jump_threshold_dps = 10000.0f;  // 10000°/s → 20° per cycle @ 500Hz (~1.4× motor max)
// Oscillation detection: safety feature that detects dangerous oscillations and triggers emergency stop
volatile uint16_t osc_window_ms = 500;              // Time window to count error sign changes (default: 500ms)
volatile uint8_t osc_min_sign_changes = 4;           // Min sign changes to trigger (4 = 2 full oscillations)
volatile float osc_min_amplitude_deg = 3.0f;         // Min oscillation amplitude to be considered dangerous (°)
volatile float osc_min_error_to_check = 1.0f;        // Don't check oscillation if error below this (°)
// Compliance control (deflection/stall, anti-slack, soft hold)
volatile float expected_velocity_deadband_deg_s = 1.0f;
volatile float outer_hold_ki_scale = 0.10f;
volatile uint16_t outer_hold_ki_ramp_ms = 1000;
volatile float outer_hold_integral_freeze_error_deg = 0.25f;
volatile float outer_hold_integral_freeze_velocity_deg_s = 0.5f;
volatile bool retension_probe_enabled = false;
volatile float retension_probe_boost_deg = 3.0f;
volatile uint16_t retension_probe_pulse_ms = 250;
volatile uint16_t retension_probe_start_delay_ms = 2000;
volatile uint16_t retension_probe_post_ms = 800;
volatile uint16_t retension_probe_repeat_ms = 30000;
volatile float retension_probe_min_hold_q_deg = 0.0f;
volatile uint16_t diag_hold_min_samples = 1;
volatile uint16_t diag_hold_ema_settled_samples = 500;
volatile uint16_t diag_hold_period_ms = 500;
volatile uint16_t diag_move_period_ms = 20;   // Period of [DIAG_MOVE] motion telemetry (~50 Hz) — TELEMETRY ONLY
volatile uint16_t trim_dry_run_min_samples = 7500;
volatile uint16_t trim_dry_run_period_ms = 3000;
volatile bool compliance_detection_enabled = false;
volatile float hold_error_threshold_deg = 6.0f;
volatile uint16_t hold_time_threshold_ms = 120;
volatile float hold_release_threshold_deg = 2.0f;
volatile float hold_release_velocity_deg_s = 1.0f;
volatile float hold_release_max_velocity_deg_s = 30.0f;  // Max velocity for error-based release
volatile uint16_t hold_release_time_ms = 150;
volatile float move_error_threshold_deg = 8.0f;
volatile float move_velocity_ratio = 0.2f;
volatile uint16_t move_time_threshold_ms = 300;
volatile uint8_t velocity_filter_samples = 5;
volatile float anti_slack_margin_deg = 5.0f;
volatile bool anti_slack_enabled = false;
volatile float soft_hold_torque_ratio = 0.3f;   // 30% torque during compliance
volatile float min_tension_torque = 20.0f;
volatile uint16_t soft_hold_ramp_down_ms = 600;   // Torque release ramp (ms)
volatile uint16_t soft_hold_ramp_up_ms = 800;     // Torque recovery ramp (ms)
volatile bool soft_hold_enabled = false;
volatile bool friction_ff_enabled = false;          // OPT-IN (default OFF): the friction-FF is now the GMS
                                                     // break-away bristle (updateGmsFriction), validated OFFLINE
                                                     // only -> arm per bench session via CAN 0x015 param0=1.
volatile float friction_ff_torque = 30.0f;          // Now Fs = the GMS break-away level (offline seed ~55); tune via 0x015
volatile float friction_ff_speed_thresh = 3.0f;     // GMS sigma1 OVER-SLIP DAMPING (bench-validated 3.0), NOT a speed
                                                     // gate (the old trapezoidal gate is gone; name kept for ABI).
volatile bool cascade_slope_scaling_enabled = false; // OPT-IN (default OFF): per-tendon dth slope scaling S_x/S_bar
                                                     // in the cascade formula (review P1 2026-07-02, range-extremes
                                                     // defect); toggle via IMPEDANCE_CTRL 0x06.
volatile bool sched_interleave_enabled = false;      // OPT-IN (default OFF = the historical serial order): O1 strict
                                                     // interleave of the per-DOF motor-CAN pair round-trips in the
                                                     // control loop (500Hz Stage 1); IMPEDANCE_CTRL 0x08 bit0.
volatile bool sched_carry_enabled = false;           // OPT-IN (default OFF): Stage-2 cross-cycle CARRY — the last pair
                                                     // fired in a cycle stays in flight across the boundary and re-enters
                                                     // the Stage-1 pending machinery next cycle; IMPEDANCE_CTRL 0x08 bit1.
volatile bool sched_sub92_enabled = false;           // OPT-IN (default OFF): Stage-2 SUBSTITUTE-FIRE 0x92 — on a watchdog-due
                                                     // cycle the DOF fires the 2-frame 0x92 pair INSTEAD of the torque pair
                                                     // (same <=2-frame footprint), motors hold the previous torque one cycle
                                                     // (ZOH), and the reply is carried + compared next cycle; IMPEDANCE_CTRL 0x08 bit2.
volatile float friction_ff_torque_neg = 0.0f;        // GMS Fs for the NEGATIVE commanded direction; 0 = symmetric
                                                     // (use friction_ff_torque both ways). The knee 2x2 showed the
                                                     // FF SHIFTS the direction asymmetry instead of removing it ->
                                                     // per-direction Fs is the evidence-backed lever (0x015 param 3).
volatile ComplianceRecoveryPolicy recovery_policy = RECOVERY_STAY_AT_CURRENT;
volatile uint16_t recovery_ramp_back_ms = 1000;
ComplianceState compliance_state[MAX_DOFS] = {};
// command array
char command[100];
// SERVO CANBUS (J4 CAN_Servo - Motor communication)
MCP_CAN CAN(&SPI1, CAN_CS_PIN);
// HOST CANBUS (J5 CAN_Controller - Host/Jetson communication)
MCP_CAN CAN_HOST(&SPI1, CAN_HOST_CS_PIN);

// NOTE: Direct encoder reading (DirectEncoders) is configured and initialized
// in setup() after determining the number of DOFs for the active joint.
// The global instance 'directEncoders' is defined in DirectEncoders.cpp

// Time offset for synchronization
float time_offset = 0;

// Encoder test flags (Serial - Core0)
bool encoder_test_active             = false;
uint8_t encoder_test_joint_id        = 0;
uint8_t encoder_test_dof_index       = 0;
bool encoder_test_all_dofs           = false; // NEW: test all DOFs
unsigned long last_encoder_test_time = 0;

// Encoder streaming via CAN (high-frequency - Core1)
volatile bool encoder_stream_can_active = false;
volatile uint32_t encoder_stream_last_send_us = 0;

// Core1 → Core0 flag: request safe limits emission via Serial
volatile bool emit_safe_limits_requested = false;

// Joint identification broadcast (triggered via CAN, emitted on Serial + CAN)
volatile bool identify_broadcast_active = false;
volatile uint32_t identify_broadcast_start_ms = 0;
const uint32_t IDENTIFY_BROADCAST_DURATION_MS = 3000;  // Broadcast for 3 seconds
const uint32_t IDENTIFY_BROADCAST_INTERVAL_MS = 500;   // Emit every 500ms
volatile uint32_t identify_broadcast_last_emit_ms = 0;
volatile uint32_t identify_can_announce_last_ms = 0;    // CAN announce timing (Core1)

// CAN-triggered startup sequence (Core1 sets flag, Core0 executes)
volatile bool can_startup_requested = false;
volatile uint8_t can_startup_joint_id = 0;
volatile int16_t can_startup_torque = 0;
volatile int16_t can_startup_duration = 0;

// CAN-triggered set-zero (Core1 sets flags, Core0 executes)
volatile bool can_set_zero_requested = false;
volatile uint8_t can_set_zero_dof_index = 0;

// CAN encoder offset notification (Core0 sets flag, Core1 sends CAN frames)
volatile bool can_encoder_offsets_notify = false;

// CAN-triggered PID flash operations (Core1 sets flag, Core0 executes)
volatile bool can_save_pid_requested = false;
volatile bool can_load_pid_requested = false;

// CAN-triggered linear equations flash ops (Core1 sets flag, Core0 executes)
volatile bool can_save_linear_eq_requested = false;
volatile bool can_load_linear_eq_requested = false;

// CAN-triggered fine-map (piecewise) flash save (Core1 sets flag, Core0 executes)
volatile bool can_save_fine_map_requested = false;

// CAN-triggered 2D bilinear grid flash save (Core1 sets flag, Core0 executes)
volatile bool can_save_grid_requested = false;

// CAN-triggered auto-start setting (Core1 sets params + flag, Core0 executes flash save)
volatile bool can_set_auto_start_requested = false;
volatile uint8_t can_auto_start_enabled = 0;
volatile int16_t can_auto_start_torque = 0;
volatile uint16_t can_auto_start_duration = 0;

// CAN firmware update flash operations
FirmwareUpdateCoreRequest fw_update_core_request = {};
FirmwareUpdateCoreResponse fw_update_core_response = {};
volatile bool fw_update_metadata_snapshot_valid = false;
FirmwareUpdateMetadataRecord fw_update_metadata_snapshot = {};

// Startup status event queue (Core0 produces, Core1 consumes and sends via CAN)
queue_t startup_event_queue;

// Diagnostic event queue (Core1 producers, Core1 CAN sender)
queue_t diag_event_notice_queue;

// PID diagnostics for tuning (updated by Core1 control loop)
PIDDiagnostics pid_diagnostics = {0};
volatile bool pid_diag_stream_active = false;
volatile bool pid_diag_terms_enabled = false;  // OFF by default — P/I/D breakdown
// Root-fix A/B flag: feed the PID's time-scaled terms (I/D/filter) the REAL measured loop dt
// (gms_dt_s) instead of the fixed member Ts. OFF by default so the bench can A/B the oscillation
// fix against the gain re-tune via CAN_ID_PID_MEASURED_DT_CTRL without a reflash.
volatile bool pid_measured_dt_enabled = false;

// Holding diagnostics (Phase 1 — written by core0, read by core1 for CAN send)
DiagHoldData diag_hold_data[MAX_DOFS] = {};
RetensionProbeResultData retension_probe_result_data[MAX_DOFS] = {};

// Cached motor angles (for safety checks without redundant CAN reads)
// This eliminates the ~2ms delay per motor during periodic safety checks
CachedMotorAngles cached_motor_angles = {
    .agonist = {0, 0, 0},
    .antagonist = {0, 0, 0},
    .valid = {false, false, false},
    .last_update_ms = 0
};

// Movement metrics for PID tuning evaluation
MetricsTracker metrics_tracker[3] = {};
MovementMetrics last_movement_metrics[3] = {};
volatile bool metrics_ready[3] = {false, false, false};
volatile bool metrics_tracking_enabled = true;  // Enable by default

// Global variable for auto‑mapping state
AutoMappingState_t auto_mapping_state = {0};

// DOF control state
volatile DofState dof_state[MAX_DOFS] = {DofState::IDLE, DofState::IDLE, DofState::IDLE};
volatile float dof_hold_angle[MAX_DOFS] = {0};
volatile uint32_t dof_hold_time[MAX_DOFS] = {0};

// Impedance control state (Scenario B — SET_IMPEDANCE CAN command)
ImpedanceTarget impedance_target[MAX_DOFS] = {};
ImpedanceRollingSegment impedance_segment[MAX_DOFS] = {};
volatile uint32_t impedance_watchdog_ms = 100;  // 100ms default watchdog
InnerPidBackup inner_pid_backup[MAX_DOFS][2] = {};  // [dof][0=agonist, 1=antagonist]
OuterLoopBackup outer_loop_backup[MAX_DOFS] = {};
volatile bool inner_pid_reinit_after_impedance[MAX_DOFS] = {};
volatile uint8_t inner_actuation_mode[MAX_DOFS] = {
    INNER_ACTUATION_LOOP1_TORQUE,
    INNER_ACTUATION_LOOP1_TORQUE,
    INNER_ACTUATION_LOOP1_TORQUE,
};
volatile uint16_t loop2_angle_max_speed[MAX_DOFS] = {
    LOOP2_DEFAULT_ANGLE_MAXSPEED,
    LOOP2_DEFAULT_ANGLE_MAXSPEED,
    LOOP2_DEFAULT_ANGLE_MAXSPEED,
};
volatile uint16_t loop2_target_step_x100[MAX_DOFS] = {
    LOOP2_DEFAULT_TARGET_STEP_X100,
    LOOP2_DEFAULT_TARGET_STEP_X100,
    LOOP2_DEFAULT_TARGET_STEP_X100,
};

// Control flag for sending mapping data
bool auto_mapping_data_ready_to_send = false; // true = auto‑mapping data ready to send to host

// NOTE: movement safety is handled by JointController::isSystemReadyForMovement()
// which checks linear equations availability and calibrated offsets

#pragma endregion

#pragma region SharedData
// Data structures for multi‑joint support
shared_data_extended_t shared_data_ext       = {0};
command_data_extended_t command_data_ext     = {0};
measuring_data_extended_t measuring_data_ext = {0};

// Command parser
CommandParser command_parser;

// Active joint controller
JointController *active_joint_controller = nullptr;

using MovementSample = movement_sample_t;

queue_t movement_sample_queue;
queue_t core1_log_queue;
volatile bool movement_sample_stream_active = false;
volatile bool movement_sample_stream_done   = false;
volatile uint8_t movement_sample_joint_id   = 0;
volatile bool movement_sample_overflow      = false;
uint16_t movement_sample_counters[MAX_DOFS] = {0};

// === SHARED DOF ANGLES (Updated by Core0, read by Core1) ===
SharedDofAngles shared_dof_angles = {
  .seq = 0,
  .angles = {0},
  .velocities = {0},
  .timestamp_us = 0,
  .valid = {false, false, false},
  .updated = false,
  .dof_count = 0
};

// === NEW INTER‑CORE COMMUNICATION SYSTEM ===
// Double‑buffered command passing
command_data_extended_t command_buffer[2] = {0};
volatile int active_buffer                = 0;
volatile bool buffer_ready[2]             = {false, false};
volatile uint8_t pending_command_type     = 0;
#if MOTION_GUARD_V2
volatile uint8_t motion_guard_mode        = 0;  // MG2-S: 0 LEGACY / 1 SHADOW / 2 ACTIVE (RAM-only)
#endif

// Separate emergency flag for extra safety (atomic for cross-core access)
std::atomic<bool> emergency_stop_requested{false};

// Array of active controllers accessible from core1 (indices 1..6 for joints)
JointController *active_controllers[9] = {nullptr}; // Index 0 not used, joint IDs 1..8

// Active controller state for current cycle
uint8_t current_joint_id  = 0;
uint8_t current_dof_index = 0;


#pragma endregion

// ============================================================================
// CORE LOOP IMPLEMENTATIONS
// ============================================================================
// Core0 loop (serial communication) is implemented in core0.cpp
// Core1 loop (hardware operations) is implemented in core1.cpp
// Both are declared in main_common.h and linked automatically by PlatformIO

// Helper: MCP2515 CAN loopback test — verifies SPI + chip communication
// Returns true if TX→RX loopback succeeded with matching data
bool can_loopback_test(MCP_CAN &can, const char* label,
                              unsigned long test_id, const unsigned char test_data[8]) {
  if (can.setMode(MCP_LOOPBACK) != CAN_OK) {
    LOG_ERROR(String(label) + " failed to enter loopback mode — SPI problem");
    return false;
  }

  byte send_result = can.sendMsgBuf(test_id, 0, 8, const_cast<unsigned char*>(test_data));
  if (send_result != CAN_OK) {
    LOG_ERROR(String(label) + " loopback TX failed (code " + String(send_result) + ")");
    can.setMode(MCP_NORMAL);
    return false;
  }

  delay(10);

  if (can.checkReceive() != CAN_MSGAVAIL) {
    LOG_ERROR(String(label) + " loopback RX: no message received");
    can.setMode(MCP_NORMAL);
    return false;
  }

  unsigned long rx_id;
  unsigned char rx_len;
  unsigned char rx_buf[8];

  if (can.readMsgBuf(&rx_id, &rx_len, rx_buf) != CAN_OK) {
    LOG_ERROR(String(label) + " loopback RX read failed");
    can.setMode(MCP_NORMAL);
    return false;
  }

  bool match = (rx_id == test_id) && (rx_len == 8);
  for (int i = 0; i < 8 && match; i++) {
    if (rx_buf[i] != test_data[i]) match = false;
  }

  // If first read had stale data, try second read
  if (!match && can.checkReceive() == CAN_MSGAVAIL) {
    LOG_WARN(String(label) + " first RX was stale, trying second read...");
    if (can.readMsgBuf(&rx_id, &rx_len, rx_buf) == CAN_OK) {
      match = (rx_id == test_id) && (rx_len == 8);
      for (int i = 0; i < 8 && match; i++) {
        if (rx_buf[i] != test_data[i]) match = false;
      }
    }
  }

  if (match) {
    LOG_INFO(String(label) + " loopback PASSED");
  } else {
    LOG_ERROR(String(label) + " loopback DATA MISMATCH");
  }

  if (can.setMode(MCP_NORMAL) != CAN_OK) {
    LOG_ERROR(String(label) + " failed to return to normal mode");
  }

  return match;
}

struct CrossChipCanStats {
  uint16_t iterations = 0;
  uint16_t send_failures = 0;
  uint16_t rx_timeouts = 0;
  uint16_t rx_read_failures = 0;
  uint16_t rx_mismatches = 0;

  bool passed() const {
    return send_failures == 0 &&
           rx_timeouts == 0 &&
           rx_read_failures == 0 &&
           rx_mismatches == 0;
  }
};

static void flush_can_rx(MCP_CAN &can) {
  unsigned long id;
  unsigned char len;
  unsigned char buf[8];
  while (can.checkReceive() == CAN_MSGAVAIL) {
    can.readMsgBuf(&id, &len, buf);
  }
}
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
void loop() {
  core0_main_loop();
}

#pragma endregion

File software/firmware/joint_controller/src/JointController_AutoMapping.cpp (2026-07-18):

/**
 * @file JointController_AutoMapping.cpp
 * @brief Automatic calibration (auto-mapping) implementation for JointController
 * 
 * This file contains the implementation of JointController methods related to:
 * - Starting and stopping automatic mapping/calibration
 * - Moving between mapping points
 * - Acquiring calibration data at each point
 * - Applying torques and speeds during calibration
 * - Verifying position stability and completion
 * - Transferring acquired data to mapping structures
 * 
 * These methods are part of the JointController class but separated here
 * for better code organization and maintainability.
 */

#include <JointController.h>
#include <commands.h>
#include <debug.h>
#include <utils.h>
#include <algorithm>
#include <hardware/sync.h>  // __dmb() cross-core memory barrier (pico-sdk)
#include "main_common.h"
#include <hot_path.h>  // For shared_dof_angles

namespace {
bool isActiveAutoMappingDof(const AutoMappingState_t &state, uint8_t dof_index) {
  for (int i = 0; i < state.active_dof_count; i++) {
    if (state.active_dof_indices[i] == dof_index) {
      return true;
    }
  }
  return false;
}
}

// External variables for inter-core communication
// Note: emergency_stop_requested, buffer_ready, active_buffer, pending_command_type
// are declared in main_common.h (included above)

// ============================================================================
// AUTOMATIC CALIBRATION (AUTO-MAPPING)
// ============================================================================

// Start automatic mapping for all DOFs of the joint
bool JointController::startAutoMapping(AutoMappingState_t &auto_mapping_state,
                                       float tensioning_torque, float *steps, int settle_time_ms) {
  // S2 CARRY choke point (MAJOR amendment): auto-mapping is a SEPARATE state machine that replaces
  // executeControlLoop (and thus the carry-injection resolve) and drives the motor bus. Abandon any
  // carried pair before it starts, so a carried pair's replies aren't orphaned. Core-affinity guarded.
  abandonCarriedPair();
  // Validate input parameters
  if (config.dof_count == 0) {
    LOG_C1_ERROR("No DOF configured for this joint");
    return false;
  }

  if (config.motor_count == 0) {
    LOG_C1_ERROR("No motors configured for this joint");
    return false;
  }

  uint8_t active_dof_indices[MAX_DOFS] = {0};
  int active_dof_count = 0;
  for (int i = 0; i < config.dof_count; i++) {
    if (dofSupportsAutoMapping(i)) {
      active_dof_indices[active_dof_count++] = static_cast<uint8_t>(i);
      continue;
    }

    if (config.dofs[i].drive_type == DRIVE_DIRECT_DRIVE) {
      LOG_C1_INFO("Skipping auto mapping for DOF " + String(i) + " (" +
                  String(config.dofs[i].name) + ") - direct-drive DOF");
      continue;
    }

    LOG_C1_ERROR("Auto mapping not supported for DOF " + String(i) + " (" +
                 String(config.dofs[i].name) + ")");
    return false;
  }

  if (active_dof_count == 0) {
    LOG_C1_ERROR("No tendon DOFs available for auto mapping");
    return false;
  }

  // Verify that each DOF has at least 2 motors (agonist and antagonist)
  for (int idx = 0; idx < active_dof_count; idx++) {
    int i = active_dof_indices[idx];
    int motor_count_for_dof = 0;
    bool has_agonist = false, has_antagonist = false;

    for (int j = 0; j < config.motor_count; j++) {
      if (config.motors[j].dof_index == i) {
        motor_count_for_dof++;
        if (config.motors[j].is_agonist) {
          has_agonist = true;
        } else {
          has_antagonist = true;
        }
      }
    }

    if (motor_count_for_dof < 2 || !has_agonist || !has_antagonist) {
      LOG_C1_ERROR("DOF " + String(i) + " does not have correctly configured agonist/antagonist motors");
      return false;
    }
  }

  // Reset counters before starting
  auto_mapping_state.consecutive_encoder_errors = 0;
  auto_mapping_state.last_valid_reading         = millis();
  LOG_C1_DEBUG("Initializing auto mapping counters");

  // Verify if auto‑mapping is already active
  if (auto_mapping_state.active) {
    LOG_C1_ERROR("Auto mapping already in progress");
    return false;
  }

  // Initialize mapping state
  memset(&auto_mapping_state, 0, sizeof(AutoMappingState_t));

  // IMPORTANT: Completely reset existing mapping structures to avoid conflicts
  for (int i = 0; i < config.dof_count; i++) {
    dof_mappings[i].size = 0;
    dof_mappings[i].flag = 0;
    // Optionally, reset data for safety
    memset(dof_mappings[i].agonist_data, 0, sizeof(dof_mappings[i].agonist_data));
    memset(dof_mappings[i].antagonist_data, 0, sizeof(dof_mappings[i].antagonist_data));
    memset(dof_mappings[i].joint_data, 0, sizeof(dof_mappings[i].joint_data));
  }
  LOG_C1_DEBUG("DofMappingData_t structures reset for new mapping");

  // Set first_call flag to ensure array initialization
  auto_mapping_state.first_call = true;
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

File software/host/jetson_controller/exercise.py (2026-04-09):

"""
Headless Jetson exercise runner.

Runs the normal CAN startup path, starts the impedance loop, then executes a
repeatable target pattern across the selected joints/DOFs for a fixed duration.
"""
from __future__ import annotations

import argparse
import asyncio
import json
import logging
import sys
import time
from dataclasses import dataclass
from pathlib import Path

from .can_bus import CanBus
from .config import ControllerConfig, JointControlConfig, load_config
from .fsm import StartupFSM
from .impedance_loop import ImpedanceLoop
from .safety import SafetyManager
from .serial_monitor import discover_ports, preflight_boot
from .session_log import get_log_path, setup_session_logging
from .telemetry import TelemetryManager
from .protocol import encode_encoder_stream_ctrl, encode_loop_frequency

logger = logging.getLogger("jetson_controller.exercise")

CAN_PREFLIGHT_TIMEOUT_S = 1.5
CAN_PREFLIGHT_HOST_ERROR_LIMIT = 64
CAN_PREFLIGHT_MOTOR_ERROR_LIMIT = 32
CAN_PREFLIGHT_EFLG_FATAL_MASK = 0x38  # TXBO | TXEP | RXEP


@dataclass(frozen=True)
class ExerciseStep:
    joint_key: str
    dof: int
    target_deg: float


@dataclass(frozen=True)
class ExerciseDofPlan:
    joint_key: str
    dof: int
    center_deg: float
    targets_deg: list[float]


def _write_run_report(path: str, payload: dict[str, object]) -> None:
    report_path = Path(path)
    report_path.parent.mkdir(parents=True, exist_ok=True)
    report_path.write_text(
        json.dumps(payload, indent=2, sort_keys=True) + "\n",
        encoding="utf-8",
    )


def setup_logging(verbose: bool = False) -> None:
    root = logging.getLogger()
    root.setLevel(logging.DEBUG)

    console = logging.StreamHandler()
    console.setLevel(logging.INFO)
    console.setFormatter(logging.Formatter(
        "%(asctime)s.%(msecs)03d %(levelname)-7s [%(name)s] %(message)s",
        datefmt="%H:%M:%S",
    ))
    root.addHandler(console)

    logging.getLogger("can").setLevel(logging.WARNING)

    setup_session_logging(verbose, clear=True)
    logger.info(f"Session log: {get_log_path()}")


def _collect_preflight_ports(preflight_auto: bool,
                             preflight_serials: list[str] | None) -> list[str]:
    ports: list[str] = []
    if preflight_serials:
        for port in preflight_serials:
            if port not in ports:
                ports.append(port)
    if preflight_auto:
        for port in discover_ports(verbose_output=False):
            if port not in ports:
                ports.append(port)
    return ports


def _safe_window(jcfg: JointControlConfig, dof: int, margin_deg: float) -> tuple[float, float]:
    safe_min = float(jcfg.min_angles[dof]) + margin_deg
    safe_max = float(jcfg.max_angles[dof]) - margin_deg
    if safe_min > safe_max:
        raise ValueError(
            f"Invalid safe window for {jcfg.name} DOF{dof}: "
            f"min={safe_min:.1f} max={safe_max:.1f}"
        )
    return safe_min, safe_max


def _build_plans(config: ControllerConfig,
                 span_cap_deg: float,
                 margin_deg: float,
                 min_excursion_deg: float) -> list[ExerciseDofPlan]:
    plans: list[ExerciseDofPlan] = []

    for key, jcfg in config.joints.items():
        for dof in range(jcfg.dof_count):
            safe_min, safe_max = _safe_window(jcfg, dof, margin_deg)
            center = (safe_min + safe_max) / 2.0
            pos_span = max(0.0, min(span_cap_deg, safe_max - center))
            neg_span = max(0.0, min(span_cap_deg, center - safe_min))

            targets: list[float] = []
            if pos_span >= min_excursion_deg:
                targets.append(center + pos_span)
            if abs(center - (targets[-1] if targets else 1e9)) >= 0.1:
                targets.append(center)
            if neg_span >= min_excursion_deg:
                targets.append(center - neg_span)
                if abs(targets[-1] - center) >= 0.1:
                    targets.append(center)

            deduped: list[float] = []
            for target in targets:
                if not deduped or abs(deduped[-1] - target) >= 0.1:
                    deduped.append(target)

            if not deduped:
                continue

            plans.append(
                ExerciseDofPlan(
                    joint_key=key,
                    dof=dof,
                    center_deg=center,
                    targets_deg=deduped,
                )
            )

    return plans


def _interleave_steps(plans: list[ExerciseDofPlan]) -> list[ExerciseStep]:
    per_dof_sequences = [
        [ExerciseStep(plan.joint_key, plan.dof, target) for target in plan.targets_deg]
        for plan in plans
    ]
    interleaved: list[ExerciseStep] = []
    idx = 0
    while True:
        added = False
        for seq in per_dof_sequences:
            if idx < len(seq):
                interleaved.append(seq[idx])
                added = True
        if not added:
            break
        idx += 1

    return interleaved


async def _wait_for_target(telemetry: TelemetryManager, joint_key: str, dof: int,
                           target_deg: float, tolerance_deg: float,
                           timeout_s: float) -> bool:
    deadline = time.monotonic() + timeout_s
    target_map = {joint_key: {dof: target_deg}}

    while time.monotonic() < deadline:
        if telemetry.dofs_at_target(target_map, tolerance_deg)[joint_key][dof]:
            return True
        await asyncio.sleep(0.05)
    return False


def _move_timeout(current_deg: float, target_deg: float,
                  speed_deg_s: float) -> float:
    travel = abs(target_deg - current_deg)
    return max(2.5, (travel / max(speed_deg_s, 1.0)) + 2.0)
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

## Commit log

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2025-11-05 feat(host-ui): improve UI layout and fix auto-mapping grid calculation
    - Fix auto-mapping grid: use auto_mapping_min/max_angle from firmware config
    instead of physical joint limits (e.g., ANKLE: 25 points instead of 176)
    - Add /joint_config endpoint to serve joint configuration from JSON
    - Extract auto-mapping parameters (min/max angle, step) in extract_joint_config.py
    - Regenerate joint_config.json with auto-mapping parameters from config_presets.h
    UI improvements:
    - Reorganize layout: two-column design (1/3 config, 2/3 operations)
    - Add collapsible sections for all panels (10 sections total)
    - Move Joint Selection to left column with collapse functionality
    - Improve toggle UI: compact l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
    [routes.py]
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2025-11-06 fix(time-sync): use existing serial connection to prevent data corruption
    - Replace separate serial connection with existing self.serial_connection
    - Add 0.1s delay after pause_listening() for thread synchronization
    - Clear both input and output buffers before sync
    - Use flush() to ensure immediate command transmission
    - Reduce timeout to 1s (sufficient for USB communication)
    - Add small delay in read loop to avoid busy-waiting
    - Fix intermittent sync failures and character corruption issues
    [core0.cpp]
2025-11-06 feat: enhance NTP time synchronization with drift tracking and human-readable output
    - **Serial Handler**:
    - Use time.perf_counter() for stable monotonic time reference
    - Track baseline offset and calculate drift on subsequent syncs
    - Calculate firmware boot time from offset
    - Add comprehensive timing metadata (uptime, boot epoch, ISO timestamps)
    - Open dedicated temporary serial connection to avoid conflicts
    - **Backend (routes.py)**:
    - Return enriched sync data with drift, boot time, and quality metrics
    - Quality thresholds: <10ms=good, <50ms=fair, >50ms=poor
    - **Frontend (scripts.js)**:
    - Display human-readable durations (e.g., '1h 23m 45.678s')
    - Show offset drift vs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
    [routes.py]
2025-11-06 fix(firmware): correct inconsistent switch case indentation in core0.cpp
    The CMD_GET_PID, CMD_SET_PID, CMD_GET_PID_OUTER, CMD_SET_PID_OUTER, CMD_SAVE_PID, CMD_LOAD_PID, CMD_START_TEST_ENCODER, CMD_STOP_TEST_ENCODER, and CMD_GET_MOVEMENT_DATA cases had misaligned indentation (16 spaces instead of 20), causing them to be outside the main switch statement scope. This prevented these commands from executing properly, particularly GET_PID which was not responding with EVT:PID messages.
    This fix ensures all case statements are at the correct indentation level within the switch(parsed_cmd.command) block, allowing proper command routing and execution.
    [core0.cpp]
2025-11-09 feat: implement movement acknowledgment system to prevent firmware crashes
    - Add threading-based acknowledgment system in SerialHandler
    * movement_complete_event for waiting on RSP:MOVE_COMPLETE
    * movement_queue_lock to serialize movement commands
    * movement_pending flag to track execution state
    - Implement send_movement_command_with_ack() method
    * Sends movement command and waits for firmware completion signal
    * Prevents race conditions by serializing movements
    * 30s timeout with proper error handling
    - Parse RSP:MOVE_COMPLETE messages in serial listener
    * Set event when movement completes
    * Update UI with completion status
    - Update /command route to use acknowledgment fo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
    [routes.py]
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2025-11-14 fix(routes): Add missing handler retrieval in sequence endpoints
    Fixed linter errors where 'handler' variable was undefined in:
    - /sequence/start
    - /sequence/stop
    - /sequence/data
    Now properly retrieves handler using handler_or_error(joint) with
    joint parameter from request body/args.
    [routes.py]
2025-11-17 feat(can): optimize CAN ID allocation for motor control priority
    - Reorganize CAN ID ranges to prioritize motor commands over waypoints
    - Motor torque commands (0x140-0x280) now have higher priority than waypoints
    - Waypoints moved from 0x010-0x06F to 0x300-0x31F (Priority Level 3)
    - Status feedback moved from 0x200-0x3FF to 0x400-0x4FF (Priority Level 4)
    Priority allocation:
    - Level 0 (Highest): Emergency Stop (0x000)
    - Level 1 (System): Time Sync (0x002)
    - Level 2 (CRITICAL): Motor Commands (0x140-0x280) @ 500 Hz
    - Level 3 (Trajectory): Waypoints (0x300-0x31F) @ 50-100 Hz
    - Level 4 (Lowest): Status (0x400-0x4FF) @ 10-50 Hz
    This ensures PID loop stability by preventing waypoint messages f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
    [can_manager.py]
2025-11-17 feat(can): complete CAN control implementation with UI and firmware
    Implement full CAN bus control system for host-to-controller communication
    with Single CAN Bus architecture (merged Host + Motor CAN).
    Firmware changes:
    - Add waypoint buffer system (waypoint_buffer.h/cpp)
    - Add SPI1 lock for safe CAN access (spi1_lock.h/cpp, mcp_can_guard.h)
    - Implement CAN polling in core1_loop (pollUnifiedCan)
    - Add Time Sync, Emergency Stop, and Waypoint handlers
    - Move all CAN management to Core1 to avoid SPI conflicts
    - Update PINOUT.md with CAN interface documentation
    - Remove HostCanInterface (dual CAN bus) in favor of unified bus
    Host changes:
    - Add CanManager class for python-can integration
    - Ad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
    [JointController.cpp, core0.cpp, main.cpp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]
2025-11-17 refactor(can): remove obsolete SPI1 lock files
    Remove SPI1 lock implementation as it's no longer needed with the
    Single CAN Bus architecture where Core1 has exclusive access to the
    CAN bus.
    Removed files:
    - include/spi1_lock.h
    - src/spi1_lock.cpp
    - include/mcp_can_guard.h (was just a passthrough)
    Updated files:
    - src/main_common.h: Remove spi1_lock and mcp_can_guard includes
    - src/main.cpp: Remove spi1_lock_init() call
    - lib/LKM_Motor/LKM_Motor.h: Include mcp_can.h directly
    Rationale:
    With Core1 having exclusive access to the CAN bus (both Host and Motor
    commands), there are no race conditions or SPI1 conflicts possible.
    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
    [main.cpp, main_common.h]
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2025-11-18 feat: Implement comprehensive runtime safety checks for waypoint movement
    - Add 3-level safety system for waypoint execution:
    * Level 1 (Preventive): Safety checks at waypoint reception
    * Level 2 (Runtime): Continuous checks during MOVING mode @ 100 Hz
    * Level 3 (Transition): Immediate checks when entering HOLDING mode
    - Implement runtime safety in executeWaypointMovement():
    * Check joint limits and mapping limits every cycle in MOVING mode
    * Check motor range (tendon breakage) periodically in HOLDING mode
    * Detect MOVING → HOLDING transitions for immediate safety verification
    * Stop all motors and reset DOF state on safety violation
    - Add JointController::checkWaypointSafe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
    [JointController.cpp, JointController.h, JointController_Waypoint.cpp]
2025-11-27 feat(firmware): Dual CAN bus + waypoint interpolation system
    DUAL CAN BUS ARCHITECTURE:
    - J4 CAN_Servo (GP9/GP13): Motor commands via LKM protocol @ 500Hz
    - J5 CAN_Controller (GP8/GP14): Host commands (TimeSync, Waypoints, E-Stop)
    - Both share SPI1 with separate CS pins (no conflicts)
    - Flush stale MCP2515 messages on startup for safety
    WAYPOINT SYSTEM IMPROVEMENTS:
    - Linear interpolation @ 100Hz outer loop (200 points for 2s movement)
    - Fixed HOLDING → MOVING transition (prev_time/prev_angle update)
    - Torque limits now read from motor config (max_torque)
    - E-Stop clears waypoint buffers and exits control loop
    SAFETY ENHANCEMENTS:
    - Waypoints rejected if recalcOffset not done (isSystemRe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
    [JointConfig.h, JointController.cpp, JointController_AutoMapping.cpp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]
2025-12-02 feat(can): implement Multi-DOF Waypoint format (0x380-0x39F)
    - Add handleMultiDofWaypointFrame() in core1.cpp for optimized waypoint reception
    - Multi-DOF format sends all 3 DOFs in single 8-byte CAN frame (66% less traffic)
    - t_offset_ms uses same semantics as Single-DOF (offset from current time)
    - Sentinel value 0x7FFF marks unused DOFs for 1-DOF/2-DOF joints
    - Add send_multi_dof_waypoint() in can_manager.py
    - Add /can/multi_dof_waypoint endpoint in routes.py
    - Add format toggle in UI (Multi-DOF vs Single-DOF legacy)
    - Update CAN_SYSTEM_ARCHITECTURE.md v1.2 with corrected timing docs
    Tested: 200+ waypoint sinusoidal sequences work correctly with Multi-DOF format
    [can_manager.py, routes.py]
2025-12-02 feat(waypoint): improve CAN robustness and waypoint control stability
    Firmware improvements:
    - Increase WAYPOINT_BUFFER_DEPTH from 8 to 500 for high-density trajectories
    - Fix PID integral windup: reset error_integral_q, previous_error_q on state transitions
    - Add cycle_count overflow protection (uint16_t with modulo 1000)
    - Improve motor CAN read robustness with retries and NaN error handling
    - Add consecutive error counter for motor angle jumps (E-STOP after 3 errors)
    - Reduce motor control frequency in HOLDING mode to 100Hz (was 500Hz)
    - Increase safety check frequency in HOLDING to 200ms (was 5s)
    - Add mcp_can library for dual CAN bus support (Motor + Host)
    LKM_Motor improvements:
    - Add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
    [JointController.cpp, JointController_Waypoint.cpp, commands.h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]
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2025-12-03 feat(firmware): centralize encoder readings in Core0 with throttling and safety
    - Add SharedDofAngles struct for inter-core data sharing
    - Centralize all encoder reads in updateSharedDofAngles() on Core0
    - Throttle encoder reads to ~500Hz (2ms interval) to reduce SPI stress
    - Add emergency stop on 25 consecutive encoder failures (50ms threshold)
    - Update all modules to use shared_dof_angles instead of direct reads
    - Fix logging: I2C references changed to SPI (encoder uses SPI)
    This ensures consistent angle data across all consumers and prevents
    'Synchronization sequence not found' errors from excessive SPI polling.
    [JointController.cpp, JointController_AutoMapping.cpp, JointController_Waypoint.cpp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]
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2025-12-04 feat: Add CAN encoder streaming @ 50Hz with SLCAN support
    Firmware:
    - Add CAN ID 0x003 for encoder stream control (start/stop)
    - Add CAN ID 0x410 for encoder stream data (3 DOFs + timestamp)
    - Stream at 50Hz (20ms interval) for SLCAN compatibility
    - Fix angle unit: shared_dof_angles is already in degrees
    Host Python:
    - Add custom SLCAN listener for reliable CAN reception on macOS
    - Add encoder stream start/stop/status endpoints
    - Add SocketIO emission for real-time UI updates
    - Clear previous logs on Flask startup
    UI JavaScript:
    - Auto-select CAN streaming vs Serial polling based on connection
    - Update numeric displays and charts with stream data
    - Throttle chart updates to 10Hz for perfor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
    [can_manager.py, main.cpp, main_common.h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]
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2025-12-18 fix(electronics): Correct U4 footprint for TI DCU package (Rev B.3)
    U4 (SN74LVC2G08DCUR) footprint was wrong:
    - Old: VSSOP-8_3.0x3.0mm_P0.65mm (generic)
    - New: VSSOP-8_2.4x2.1mm_P0.5mm (TI DCU/US8)
    Issue discovered during PCBWay assembly - component didn't fit pads.
    TI's DCU package uses 0.5mm pitch, not 0.65mm.
    Updated:
    - KiCad schematic and PCB
    - Regenerated Gerber files
    - BOM and README changelog
    [BOM_SMD_PCBWay.csv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]
2025-12-20 fix(encoder): Fix SET_ZERO functionality with proper inter-core coordination
    PROBLEM:
    - SET_ZERO command was causing system freezes after first reset
    - Encoder offsets were not persisting correctly after reboot
    - Serial conflicts between Core0 and Core1 caused deadlocks
    ROOT CAUSES:
    1. Serial logging from Core1 (requestReset) conflicted with Core0 encoder data
    2. Motor encoder zeroing (CAN) was called from wrong core
    3. Flash offsets were being overwritten by defaults on init
    4. setJointOffset() had inverted semantics vs old implementation
    FIXES:
    - DirectEncoders: requestReset() now accepts target_angle_deg parameter
    - DirectEncoders: Removed Serial logging from Core1-callable functions
    -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
    [JointController.cpp, commands.h, core0.cpp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]
2025-12-21 feat: CAN encoder streaming with per-joint filtering
    - Encoder stream now uses joint-specific CAN ID (0x410 + joint_id)
    - Removed serial conflicts during movements (movement_in_progress flag)
    - Auto-mapping and linear equations calculation moved to Core0
    - Motor encoder zeroing delegated to Core1 via CMD_ZERO_MOTOR_ENCODERS
    - CAN manager decodes encoder data with joint_id from arbitration ID
    - Added joint_name to encoder stream data for UI filtering
    - Per-joint throttled logging for debugging
    UI changes:
    - SocketIO encoder_stream listener filters by joint_name
    - Removed duplicate HTTP polling (now using only SocketIO real-time)
    - Fixed chart data format to u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
    [JointController.h, JointController_AutoMapping.cpp, JointController_LinearEq.cpp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]
2025-12-24 feat: invio waypoint batch deterministico + UI sinusoide configurabile
    Modifiche principali:
    - Batch waypoint: tutti i waypoint inviati in una singola richiesta HTTP
    - Server inoltra sequenzialmente con 2ms delay per evitare overflow CAN
    - UI: parametri sinusoide configurabili (min/max angoli per DOF)
    - UI: durata ciclo singolo + visualizzazione durata totale
    - UI: display holding target durante fase di mantenimento
    - Firmware: PID outer default aggiornati (Kp=15, Ki=0.01, Cascade=1.0)
    - Firmware: max torque caviglia aumentato a 1500
    - Firmware: fix PID reset durante HOLDING (mantiene integrale)
    - Firmware: ridotti log verbosi encoder stream (10s) e CAN host (30s)
    - Fix: waypoint finale espl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
    [JointConfig.h, JointController_Waypoint.cpp, can_manager.py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]
2025-12-25 feat: movement metrics system per valutazione performance PID
    - MovementMetrics struct con rise time, settling, overshoot, SSE, torque
    - MetricsTracker per calcolo real-time durante movimento
    - Tracking da IDLE→MOVING e HOLDING→MOVING (fix per movimenti successivi)
    - Invio metriche via CAN (0x440-0x45F) a fine movimento
    - Flag metrics_tracking_enabled per disabilitare (default: true)
    - Overhead minimo (~0.1% del budget ciclo)
    Backend Python:
    - Handler per frame metriche CAN
    - Calcolo score 0-100 basato su 4 metriche
    - Emissione SocketIO evento 'movement_metrics'
    UI:
    - Sezione Movement Metrics con card per DOF 0/1
    - Display: rise time, settling, overshoot, SSE, max torque, dur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
    [JointController_Waypoint.cpp, can_manager.py, main.cpp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]
2025-12-25 fix: prevent multiple metrics tracker initialization per movement
    - Added !tracking_active guard to prevent reinitializing tracker
    when new_movement_started condition stays true for multiple cycles
    - Added detailed logging for metrics finalization (debug purposes)
    - Metrics now correctly tracked once per movement
    [JointController_Waypoint.cpp]
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2025-12-27 fix: auto-mapping acquires points on-the-fly without stopping
    PROBLEM: When leg is hanging vertically, stopping motors at each
    mapping point causes gravity to pull the joint down during the
    settle time, requiring the system to re-climb for the next point.
    SOLUTION: Acquire mapping points immediately when position is reached,
    without stopping motors or waiting for stabilization.
    Key insight: Linear regression works with any (motor_angle, joint_angle)
    pairs - the actual recorded values don't need to match the target exactly.
    Recording 5.6° instead of 5.0° is perfectly fine since we store the
    real encoder reading, not the target.
    Benefits:
    - No gravity-induced fall during mapping
    - Faster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
    [JointController_AutoMapping.cpp, main_common.h]
2025-12-27 fix: remove margin on joint physical limits for safe range calculation
    PROBLEM: Safe range was [1°, 99°] due to 1° margin on physical limits,
    excluding 0° and preventing movements to fully extended position.
    SOLUTION: Use physical limits directly from config without margin.
    The mechanical structure itself prevents dangerous overshoot beyond
    physical boundaries.
    Before: safe_min = config.min + 1° = 1° (0° excluded!)
    After: safe_min = config.min = 0° (0° included!)
    - Full range of motion available (0° to 100° for knee)
    - Movements to extended position (0°) now allowed
    - Return from mapping position to rest position possible
    - Motor safety margin (20°) preserved f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
    [JointController_LinearEq.cpp]
2025-12-27 fix: filter CAN waypoints by joint_id + add RECALC_SAFE_LIMITS command
    BUG FIX - CAN Waypoint Filtering:
    - handleMultiDofWaypointFrame() now extracts joint_id from CAN ID
    - Ignores waypoints destined for other joints on shared bus
    - Prevents ankle reacting to knee commands (and vice versa)
    NEW FEATURE - Recalculate Safe Limits:
    - CMD_RECALC_SAFE_LIMITS (ID 46) recalculates joint safe range
    - Uses current equations + physical limits from config
    - Saves updated limits to flash without re-running auto-mapping
    - Useful when limit calculation algorithm changes
    - core1.cpp: Added joint_id filter in handleMultiDofWaypointFrame()
    - commands.h: Added CMD_RECALC_SAFE_LIMITS and parsing
    - J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
    [JointController.h, JointController_Storage.cpp, commands.h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]
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2025-12-27 feat: configurable waypoint interpolation mode (linear/cosine)
    Added smooth interpolation option to reduce vibrations during movements.
    - core1.cpp: Added CAN_ID_INTERPOLATION_MODE (0x005) command handler
    - core1.cpp: Global waypoint_interpolation_mode variable (LINEAR/COSINE)
    - JointController_Waypoint.cpp: Implemented cosine S-curve interpolation
    Formula: smooth = 0.5 * (1 - cos(π * progress))
    This gives zero acceleration at start/end (no jerk)
    Host:
    - can_manager.py: set_interpolation_mode() method
    - routes.py: POST /can/interpolation_mode endpoint
    - index.html: Interpolation dropdown in Oscillation Test
    - index.html: Warning message when smooth mode selected for PID tuni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
    [JointController_Waypoint.cpp, can_manager.py, routes.py]
2025-12-27 fix: force LINEAR interpolation for batch waypoints
    Batch waypoints (sinusoids, trajectories) now automatically use LINEAR mode.
    This prevents curve distortion from applying cosine interpolation between
    closely-spaced trajectory points.
    - routes.py: set_interpolation_mode('linear') before sending batch
    - scripts.js: Removed redundant client-side mode setting for sinusoid
    Logic summary:
    - Batch waypoints: Always LINEAR (trajectory provides smoothing)
    - Oscillation test: User choice (LINEAR for PID tuning, COSINE for smooth)
    - Single waypoint: Uses current mode
    [routes.py]
2025-12-27 fix: add tolerance to angle limit checks, translate warning to English
    - JointController.cpp: Added 0.5° LIMIT_TOLERANCE to isAngleInMappingLimits()
    This prevents false rejections when encoder reads -0.02° with limit at 0°
    - index.html: Translated smooth interpolation warning from Italian to English
    [JointController.cpp]
2025-12-28 feat: add co-contraction to reduce vibrations from slack tendons
    Added 50 mNm base tension (CO_CONTRACTION) to both agonist and antagonist
    motors during waypoint movements. This keeps both tendons always under
    tension, preventing the 'slack tendon' vibrations that occur when one
    tendon is not loaded (e.g., when gravity assists movement direction).
    The PID still controls the difference between motors to generate movement,
    but the sum of tensions is always at least 2*CO_CONTRACTION.
    TODO: Make CO_CONTRACTION configurable per-DOF or adaptive based on load
    [JointController_Waypoint.cpp]
2025-12-28 fix: increase default stiffness to reduce tendon slack vibrations
    Removed ineffective torque-level co-contraction (inner PID compensates it).
    The correct solution is the stiffness_ref parameter in cascade control:
    - theta_A_ref = theta_0 + 0.5*delta_theta + 0.5*stiffness_ref
    - theta_B_ref = theta_0 + 0.5*delta_theta - 0.5*stiffness_ref
    This separates motor position references, creating constant tension on both tendons.
    - JointConfig.h: Increased PID_DEFAULT_STIFFNESS_DEG from 1.0 to 5.0 degrees
    - JointController_Waypoint.cpp: Removed direct co-contraction, added documentation
    User can adjust 'Stiffness' parameter in UI (Outer Loop section) for fine-tuning:
    - Higher stiffness = m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
    [JointConfig.h, JointController_Waypoint.cpp]
2025-12-28 feat: add torque rate limiter to reduce vibrations in slow phases
    Added rate limiting on torque commands to prevent rapid fluctuations
    that cause vibrations during slow/final movement phases.
    - MAX_TORQUE_RATE = 100 units per cycle (500 Hz = 2ms)
    - Limits rate of change to ~50000 units/second
    - Applied independently to agonist and antagonist commands
    This smooths torque commands when:
    - Approaching target position (last 10-20 degrees)
    - Moving at low speeds where encoder quantization is more visible
    - Derivative term produces noisy output
    TODO: Make MAX_TORQUE_RATE configurable
    [JointController_Waypoint.cpp]
2025-12-28 refactor: replace rate limiter with low-pass filter on torque
    Changed from rate limiting (max change per cycle) to frequency-based
    filtering (attenuates high-frequency components).
    Low-pass filter (IIR 1st order):
    filtered = alpha * input + (1-alpha) * prev_filtered
    Parameters:
    - TORQUE_FILTER_ALPHA = 0.15
    - At 500 Hz sampling: cutoff frequency ≈ 12 Hz
    - Attenuates vibrations above 12 Hz while allowing normal movement
    Benefits over rate limiter:
    - More natural response (no artificial lag)
    - Frequency-domain thinking (attenuate oscillations)
    - Smoother deceleration phases
    - Better for encoder quantization noise
    [JointController_Waypoint.cpp]
2026-01-07 feat: configurable control loop + outer PID refactoring
    Control Loop Improvements:
    - Make loop frequencies configurable (inner_loop_period_us, outer_loop_divisor)
    - Add cycle time profiling for performance analysis
    - Add trajectory diagnostics logging
    - Add cosine interpolation mode for smoother waypoints
    Vibration Reduction:
    - Add notch filter for torque resonance suppression
    - Optimize checkMotorsInRange with cached motor angles
    Outer Loop PID Refactoring:
    - Replace manual PID calculation with PID class instances
    - Add filtered derivative (tau=20ms) to reduce noise sensitivity
    - Add proper anti-windup mechanism
    - Unify PID behavior between Movement.cpp and Waypoint.cpp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
    [JointConfig.h, JointController.cpp, JointController.h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]
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2026-01-07 feat: add configurable torque rate limiting
    Add torque_ramp_time_ms parameter to limit how fast torque commands
    can change, reducing mechanical stress and vibrations.
    - Add torque_ramp_time_ms global variable (default: 100ms, 0=disabled)
    - Implement rate limiting in JointController_Waypoint.cpp
    - Rate calculated per-motor based on max_torque and loop frequency
    [JointController_Waypoint.cpp, main.cpp, main_common.h]
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2026-01-07 feat: add configurable encoder error threshold
    - Add encoder_error_threshold_ms parameter (default: 100ms, was hardcoded 50ms)
    - Calculate threshold dynamically based on actual read interval
    - Minimum 5 cycles enforced for safety
    - Improved error log with time in milliseconds
    [core0.cpp, main.cpp, main_common.h]
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
